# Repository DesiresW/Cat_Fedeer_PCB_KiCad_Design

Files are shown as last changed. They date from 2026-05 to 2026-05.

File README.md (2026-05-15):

# Comedero inteligente para gatos — PCB custom ESP32

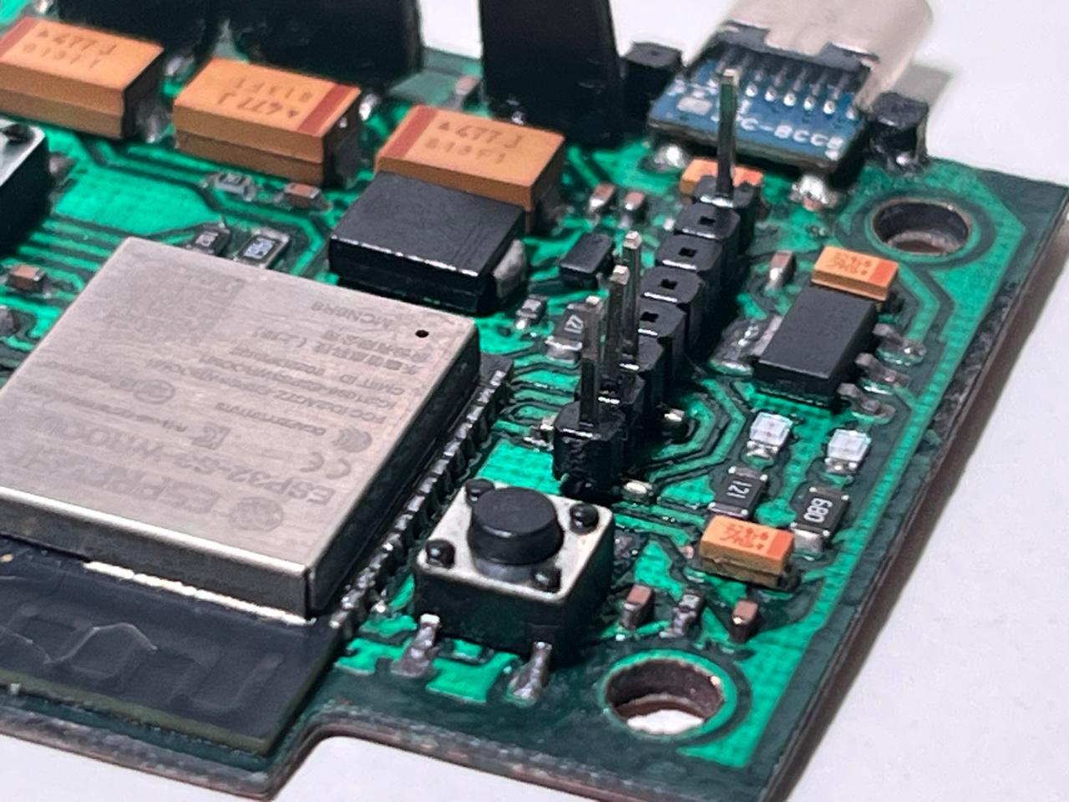
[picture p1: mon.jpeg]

## Descripción general

Este repositorio contiene el diseño de una **PCB custom basada en ESP32-S3** para un prototipo de comedero inteligente para gatos. El objetivo del proyecto no es construir una tarjeta de desarrollo genérica, sino una placa funcional orientada a controlar actuadores, leer sensores y permitir el monitoreo del comportamiento de alimentación de una mascota.

La PCB integra alimentación, programación, conexiones para sensores y actuadores, y módulos externos necesarios para el sistema. El diseño está pensado como una base de prototipado: permite validar el hardware, probar la lógica de control, registrar eventos y preparar una arquitectura donde el firmware pueda incorporar alertas o modelos simples de interpretación de comportamiento.

## Objetivo del proyecto

Diseñar y fabricar una PCB compacta, funcional y soldable que sirva como núcleo electrónico de un comedero para gatos con:

- Control de suministro sólido mediante servomotores.
- Control de motobomba para suministro líquido o sistema auxiliar.
- Medición de distancia mediante sensores ultrasónicos.
- Medición de peso mediante celda de carga y módulo HX711.
- Identificación mediante NFC.
- Alimentación regulada para el ESP32 y periféricos.
- Conexión de desarrollo separada de la conexión pensada para uso final.
- Posibilidad de integrar lógica de alertas e IA embebida en el firmware.

## Esquematico

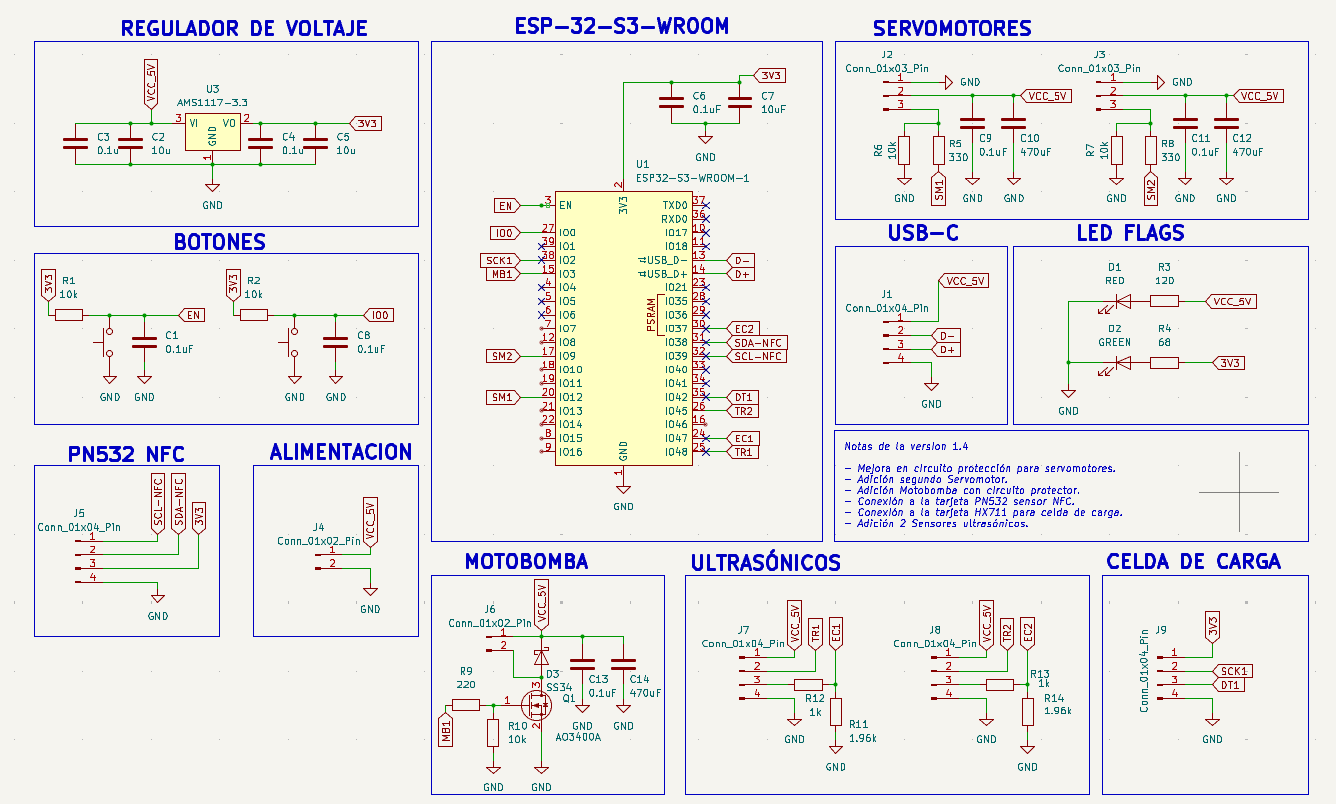
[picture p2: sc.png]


## Estado actual

El proyecto se encuentra en fase de **prototipado físico**. La PCB ya fue diseñada, fabricada, soldada y puesta en pruebas iniciales. Aún se deben validar ajustes eléctricos, mecánicos y de distribución de pines, especialmente en los elementos que dependen de integración con sensores, actuadores y carcasa.

Este repositorio documenta el diseño actual, pero no debe asumirse como una versión final de producto.

## Arquitectura general del sistema

El sistema se organiza alrededor de un microcontrolador ESP32-S3, que actúa como núcleo de control y procesamiento. La placa conecta módulos externos y componentes SMD para manejar lectura sensórica, accionamiento y alimentación.

```text
                 ┌────────────────────────┐
                 │        ESP32-S3         │
                 │  Control + firmware     │
                 └───────────┬────────────┘
                             │
        ┌────────────────────┼────────────────────┐
        │                    │                    │
 ┌──────▼──────┐      ┌──────▼──────┐      ┌──────▼──────┐
 │ Ultrasonido │      │ HX711 +     │      │ PN532 NFC   │
 │ HC-SR04 x2  │      │ celda 1 kg  │      │ + tags NFC  │
 └─────────────┘      └─────────────┘      └─────────────┘
        │                    │                    │
        └────────────────────┼────────────────────┘
                             │
                 ┌───────────▼───────────┐
                 │ Actuadores             │
                 │ Servos + motobomba     │
                 └───────────────────────┘
```

## Funcionalidades previstas

### 1. Control de actuadores

La PCB contempla conexiones para servomotores y para una motobomba controlada mediante MOSFET NMOS. La intención es separar claramente las cargas de potencia del núcleo lógico del ESP32, evitando exigir corriente desde pines o líneas que no están diseñadas para eso.

Los servomotores se plantean para mecanismos de apertura, cierre o dosificación. La motobomba se contempla como actuador auxiliar para suministro líquido o pruebas de dispensación controlada.

### 2. Medición de distancia

Se decidió usar **dos sensores ultrasónicos HC-SR04** en lugar de sensores infrarrojos de bajo costo. La decisión se tomó porque los ultrasónicos entregan una lectura continua de distancia, mientras que varios sensores infrarrojos comerciales económicos solo entregan una señal binaria ajustada por umbral.

En este prototipo, una lectura continua resulta más útil para interpretar niveles, presencia o variaciones en superficies irregulares. Además, el costo de los ultrasónicos era considerablemente menor frente a algunos sensores infrarrojos disponibles comercialmente.

### 3. Medición de peso

El sistema contempla una celda de carga de 1 kg conectada a un módulo HX711. Esta etapa permite medir cambios de peso asociados al alimento o al recipiente.

En este diseño, las conexiones entre la celda de carga y la tarjeta HX711 se consideran externas al esquemático principal de la PCB, por lo que deben revisarse directamente según el módulo y la celda utilizados.

### 4. Identificación NFC

El módulo PN532 y los tags NFC se contemplan para identificación. En el contexto del comedero, esto puede utilizarse para asociar una mascota, un recipiente, una tarjeta de configuración o un evento específico del sistema.

La implementación final depende del firmware y del flujo de uso definido para el prototipo.

### 5. Firmware e IA embebida

El hardware está pensado para recopilar datos de sensores y habilitar una capa de interpretación en firmware. La IA no toma decisiones críticas de control por sí sola; su función prevista es apoyar la clasificación de eventos y generar alertas.

Una posible clasificación de comportamiento puede incluir:

- Estado normal o sin alerta.
- Posible hambre posterior al suministro.
- Rechazo de comida.
- Consumo menor al esperado.
- Consumo mayor al esperado.
- Comportamiento atípico.

Las decisiones de seguridad, apertura, suministro adicional o activación de actuadores deben permanecer en lógica convencional validada.

## Diseño de PCB

### Enfoque

El diseño no busca replicar una DevKit comercial. La PCB fue concebida como una tarjeta específica para el comedero, con las conexiones necesarias para el proyecto y con separación entre uso final y desarrollo.

El diseño prioriza:

- Integración del ESP32-S3 como microcontrolador principal.
- Conexiones para módulos externos.
- Alimentación regulada a 3.3 V.
- Línea de 5 V para periféricos que lo requieran.
- Protección básica en líneas de alimentación y actuadores.
- Componentes SMD para reducir volumen y mejorar integración.
- Conexión de programación separada para facilitar pruebas.

### Conexión de programación

La placa incluye una conexión pensada para desarrollo/programación mediante módulo externo tipo Pololu USB-C. A diferencia de los headers de sensores y actuadores, este conector se mantiene como **macho**, porque es una conexión móvil de desarrollo.

Esta decisión permite conservar una separación entre la interfaz técnica de programación y las conexiones que usaría un usuario final.

### Headers y conectores

Para las footprints de headers se recomienda mantener la lógica definida en el prototipo:

- Headers de sensores y actuadores: **SMD y hembra**.
- Header de programación Pololu: **macho**, con footprint modificada y funcional.
- Verificar siempre el orden de pines de la huella contra el pinout real del módulo, sensor o actuador.

Este punto es crítico porque algunos módulos comerciales no respetan el mismo orden de pines entre fabricantes o versiones.

### Etiquetado de señales

Los labels del diseño se dejaron referenciando al **componente** y no necesariamente al GPIO final. Esta decisión facilita el ruteo y permite cambiar GPIOs durante la organización de pistas sin perder claridad funcional.

Por eso, antes de cerrar una nueva versión, debe revisarse la correspondencia final entre:

- Label del esquemático.
- GPIO asignado.
- Pin físico del ESP32.
- Conector o módulo externo.
- Definición usada en firmware.

## Fabricación de la PCB

La PCB fue fabricada mediante un proceso de prototipado con máquina de fibra. El flujo usado fue:

1. Definición de pistas sobre cobre mediante máquina de fibra.
2. Aplicación de máscara de soldadura sobre la placa.
3. Segunda pasada con la máquina de fibra para retirar la máscara únicamente sobre los pads.
4. Soldadura de componentes SMD y módulos de conexión.
5. Pruebas iniciales de alimentación y funcionamiento.

Este proceso permitió obtener una placa física soldable sin depender de un servicio industrial tradicional de fabricación de PCBs, aunque requiere especial cuidado en pads, continuidad, máscara y tolerancias de soldadura.

## Componentes principales

| Bloque | Componente | Función |
|---|---|---|
| Control | ESP32-S3-WROOM-1-N8R8 | Microcontrolador principal del sistema |
| Alimentación | AMS1117-3.3 | Regulación de 5 V a 3.3 V |
| Programación | Pololu USB-C | Conexión de alimentación/programación para desarrollo |
| Identificación | PN532 NFC | Lectura NFC/RFID |
| Identificación | Tags NTAG213 | Etiquetas NFC para identificación |
| Distancia | HC-SR04 x2 | Medición continua de distancia |
| Peso | HX711 | Conversión y amplificación para celda de carga |
| Peso | Celda de carga 1 kg | Medición de peso |
| Actuación | Servomotores | Apertura/cierre/dosificación |
| Actuación | Motobomba | Suministro líquido o función auxiliar |
| Potencia | AO3400 | Conmutación de motobomba |
| Protección | SS34 | Diodo Schottky para protección |
| Filtrado | Capacitores 100 nF, 10 uF, 470 uF | Estabilidad y desacople |
| Señalización | LEDs SMD | Indicadores de 5 V y 3.3 V |
| Control manual | Pulsadores SMD | Reset y modo programación |

## Lista de referencias de compra

Estos enlaces son referencias de los componentes utilizados o considerados durante el prototipo. Antes de comprar o fabricar una nueva versión, se debe verificar disponibilidad, encapsulado, dimensiones y compatibilidad con la footprint usada en KiCad.

| Componente | Referencia / enlace |
|---|---|
| PN532 NFC | https://www.mercadolibre.com.co/kit-modulo-leitor-rfid-nfc-pn532-com-tag-e-carto/p/MCO2039743778 |
| Tags NFC NTAG213 | https://www.sigmaelectronica.net/producto/ntag213-nfc/ |
| Condensador 470 uF 6.3 V SMD | https://www.sigmaelectronica.net/producto/ct2917-470uf6-3v/ |
| Sensor ultrasónico HC-SR04 | https://www.sigmaelectronica.net/producto/hc-sr04/ |
| Tarjeta HX711 | https://www.sigmaelectronica.net/producto/tarjeta-hx711/ |
| Celda de carga 1 kg | https://www.sigmaelectronica.net/producto/celda-1k/ |
| Diodo SS34 | https://www.sigmaelectronica.net/producto/ss34/ |
| MOSFET AO3400 | https://www.mercadolibre.com.co/mosfet-ao3400-a09t-sot23-smd-x-5-unidades/up/MCOU3179338761 |
| Resistencia SMD 220 Ω | https://www.sigmaelectronica.net/producto/r1206-220-ohm/ |
| Resistencia SMD 1 kΩ | https://www.sigmaelectronica.net/producto/r0805-1k/ |
| Resistencia SMD 1.96 kΩ | https://www.sigmaelectronica.net/producto/p1-96kect/ |

## Inventario resumido de soldables

La siguiente lista resume los elementos principales identificados para fabricación de varias unidades del prototipo. Las cantidades exactas deben revisarse contra el Excel de inventario y la versión actual del esquemático.

| Elemento | Valor / referencia | Encapsulado o formato | Cantidad por PCB |
|---|---:|---|---:|
| Capacitor | 0.1 uF | 0603 | 6 |
| Capacitor | 10 uF | 1206 | 3 |
| Capacitor | 470 uF | SMD | 3 |
| LED | Rojo | 0805 | 1 |
| LED | Verde | 0805 | 1 |
| Diodo | SS34 | SMC / DO-214AB | 1 |
| Header macho | Programación | SMD, mínimo 8 pines | 1 |
| Header hembra | 3 pines | SMD | 2 |
| Header hembra | 4 pines | SMD | 4 |
| Header hembra | 2 pines | SMD | 1 |
| Conector/fuente | JRC-B008 | SMD | 1 |
| MOSFET | AO3400A | SOT-23 | 1 |
| Resistencia | 10 kΩ | 0603 | 5 |
| Resistencia | 120 Ω | 1206 | 1 |
| Resistencia | 68 Ω | 1206 | 1 |
| Resistencia | 330 Ω | 0805 | 2 |
| Resistencia | 220 Ω | 1206 | 1 |
| Resistencia | 1.96 kΩ | 1206 | 2 |
| Resistencia | 1 kΩ | 0805 | 2 |
| Pulsador | Switch SMD | SMD | 2 |
| Regulador | AMS1117-3.3 | SOT-223-3 | 1 |
| MCU | ESP32-S3-WROOM-1-N8R8 | Módulo SMD | 1 |

## Módulos externos considerados

| Módulo | Cantidad por PCB | Observación |
|---|---:|---|
| PN532 NFC | 1 | Módulo externo para lectura NFC |
| Motobomba | 1 | Controlada mediante MOSFET |
| HC-SR04 | 2 | Lecturas continuas de distancia |
| Celda de carga | 1 | Conectada al HX711 |
| HX711 | 1 | Módulo de lectura para celda de carga |
| Pololu programador | 1 | Uso de desarrollo/programación |
| Header hembra Pololu | 1 | Revisar orientación y pinout |
| Servomotores | 2 | Conectores dedicados |

## Recomendaciones de diseño y revisión

### Footprints

Antes de fabricar una nueva revisión de la PCB, revisar cuidadosamente:

- Que el encapsulado del componente comprado coincida con la footprint usada.
- Que las resistencias y capacitores SMD coincidan en tamaño real con el diseño.
- Que los headers SMD tengan la orientación correcta.
- Que el orden de pines de cada módulo coincida con la huella.
- Que los pads expuestos después de la máscara de soldadura sean suficientes para soldar cómodamente.
- Que el módulo ESP32 tenga área libre adecuada para antena.

### Inventario y Excel

Para actualizar el Excel del proyecto, conviene agrupar los componentes por valor y encapsulado. No es necesario repetir cada resistencia o capacitor en filas separadas si tienen el mismo valor y la misma footprint.

Una estructura útil sería:

| Componente | Valor | Encapsulado | Cantidad por PCB | Cantidad a fabricar | Total requerido | Disponible | Faltante | Tienda | Link |
|---|---|---|---:|---:|---:|---:|---:|---|---|

También es recomendable separar la lista por tienda:

- Sigma Electrónica: mayoría de resistencias, capacitores, sensores y módulos.
- Mercado Libre: PN532 y MOSFET AO3400, si no se consigue localmente en otra tienda.
- Electronilab: ESP32-S3-WROOM-1-N8R8, según disponibilidad.
- Otro proveedor: headers SMD hembra/macho si no están disponibles en Sigma.

### Alimentación

El diseño incluye regulación para 3.3 V y líneas de alimentación para periféricos. Como recomendación general:

- No alimentar servomotores ni motobomba desde el pin de 3.3 V del ESP32.
- Separar cargas de potencia y lógica siempre que sea posible.
- Usar capacitores de desacople cerca de alimentación del microcontrolador y módulos sensibles.
- Revisar caída de tensión cuando se activen actuadores.
- Validar temperatura del regulador durante pruebas.
- Confirmar continuidad y ausencia de cortos antes de montar el ESP32.

### Sensores ultrasónicos

Los sensores HC-SR04 operan típicamente a 5 V. Antes de conectar la señal `Echo` al ESP32, se debe revisar si se requiere adaptación de nivel hacia 3.3 V para proteger el pin del microcontrolador.

### Motobomba y MOSFET

Para la motobomba se contempla un MOSFET NMOS AO3400. La etapa debe revisarse con especial atención en:

- Corriente real de la motobomba.
- Diodo de protección.
- Tierra común entre lógica y potencia.
- Ancho de pista para corriente.
- Temperatura del MOSFET en funcionamiento.
- Separación entre señal de control y carga inductiva.

### Celda de carga y HX711

La celda de carga se conecta a la tarjeta HX711. En este repositorio, las conexiones entre celda y HX711 se consideran parte del cableado externo del módulo, no del esquemático principal de la PCB.

Antes de calibrar el sistema se debe:

- Verificar cableado de la celda.
- Confirmar orientación de alimentación.
- Probar lectura cruda del HX711.
- Calibrar con pesos conocidos.
- Registrar factor de calibración en firmware.

## Estructura sugerida del repositorio

```text
.
├── README.md
├── hardware/
│   ├── kicad/
│   │   ├── esquematico/
│   │   ├── pcb/
│   │   └── gerbers/
│   ├── renders/
│   └── fabricacion/
├── firmware/
│   ├── src/
│   ├── include/
│   └── README.md
├── docs/
│   ├── img/
│   │   └── pcb-soldada.jpg
│   ├── inventario/
│   └── pruebas/
└── tools/
    └── scripts/
```

Esta estructura es solo una recomendación para mantener separados el diseño electrónico, el firmware, las imágenes, la documentación y los archivos auxiliares.

## Pruebas recomendadas

Antes de conectar todos los módulos al mismo tiempo, se recomienda validar por etapas:

### 1. Prueba de continuidad

- Verificar continuidad de GND.
- Verificar ausencia de corto entre 5 V y GND.
- Verificar ausencia de corto entre 3.3 V y GND.
- Revisar continuidad de EN, IO0 y líneas de programación.
- Revisar pads expuestos y soldaduras frías.

### 2. Prueba de alimentación

- Energizar sin ESP32 si el diseño lo permite.
- Medir 5 V.
- Medir 3.3 V.
- Revisar temperatura del regulador.
- Confirmar comportamiento de LEDs de alimentación.
- Medir consumo en reposo.

### 3. Prueba de programación

- Conectar programador.
- Verificar enumeración USB/serial.
- Probar modo boot.
- Cargar firmware mínimo.
- Confirmar salida serial.

### 4. Prueba de sensores

- Leer HC-SR04 individualmente.
- Leer HX711 sin carga.
- Calibrar celda de carga.
- Probar PN532 con tag NFC.
- Registrar estabilidad de lecturas.

### 5. Prueba de actuadores

- Probar servos por separado.
- Probar motobomba con fuente adecuada.
- Confirmar que la activación de actuadores no reinicie el ESP32.
- Medir caída de tensión durante activación.
- Revisar ruido eléctrico o reinicios.

### 6. Prueba integrada

- Ejecutar un ciclo de alimentación simulado.
- Registrar distancia, peso y eventos.
- Probar identificación NFC.
- Validar que las alertas del firmware no activen cargas sin pasar por lógica convencional.
- Documentar errores encontrados para la siguiente revisión.

## Pendientes

- Validar pinout final de todos los headers.
- Confirmar si se requiere adaptación de nivel para señales de sensores a 5 V.
- Ajustar GPIOs según facilidad de ruteo y estabilidad del firmware.
- Documentar esquema final de alimentación.
- Subir fotografías del PCB soldado.
- Agregar capturas del esquemático y layout.
- Publicar archivos KiCad organizados.
- Documentar pruebas eléctricas realizadas.
- Documentar calibración de celda de carga.
- Definir estructura final del firmware.
- Separar con claridad la lógica convencional de la capa de IA.

## Advertencia

Este proyecto está en fase de prototipado. No debe usarse como circuito final sin validar alimentación, consumo, temperatura, aislamiento, protección, corriente de actuadores y seguridad mecánica. Cualquier modificación debe revisarse en esquemático, PCB y firmware antes de energizar la placa.

## Créditos

Proyecto desarrollado como ejercicio de diseño de PCB custom, sistemas embebidos e integración sensórica aplicada a un comedero inteligente para gatos.

El diseño toma como punto de partida la idea de construir una placa propia con ESP32, pero adapta el hardware a una aplicación específica: monitoreo y control de alimentación animal mediante sensores, actuadores y procesamiento embebido.

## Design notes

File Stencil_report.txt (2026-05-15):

PCB statistics report
=====================
- Date: 6/05/2026 9:40:05 a. m.
- Project: Stencil
- Board name: Stencil

Board
-----
- Width: 60,0100 mm
- Height: 50,2500 mm
- Area: 2805,2250 mm²

Pads
----
- Through hole: 12
- SMD: 157
- Connector: 0
- NPTH: 0

Vias
----
- Through vias: 0
- Blind/buried: 0
- Micro vias: 0

Components
----------

| | Front Side | Back Side | Total |
|---|---|---|---|
|THT: | 0 | 0 | 0 |
|SMD: | 45 | 0 | 45 |
|Unspecified:  | 0 | 0 | 0 |
|Total: | 45 | 0 | 45 |

Drill holes
-----------

| Count | Shape | X Size | Y Size | Plated | Via/Pad | Start Layer | Stop Layer |
|---|---|---|---|---|---|---|---|
| 12 | Round | 0,2000 mm | 0,2000 mm | PTH | Pad | F.Cu | B.Cu |

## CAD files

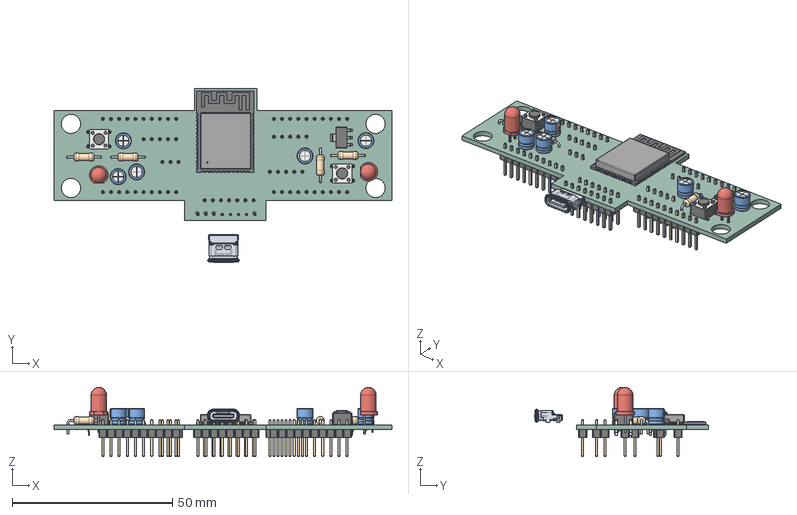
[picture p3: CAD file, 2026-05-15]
Assets/Comedero_V1.4/Stencil.step
105.4 x 54.2 x 21.6 mm
PinHeader_1x10_P2.54mm_Vertical x 4
ESP32-S3-WROOM-1
CP_Radial_D5.0mm_P2.00mm x 5
SW_PUSH_6mm x 2
PinHeader_1x03_P2.54mm_Vertical
PinHeader_1x07_P2.54mm_Vertical
PinHeader_1x08_P2.54mm_Vertical
R_Axial_DIN0207_L6.3mm_D2.5mm_P10.16mm_Horizontal x 4
LED_D5.0mm x 2
PinHeader_1x05_P2.54mm_Vertical x 3
SOT-223
Stencil_PCB

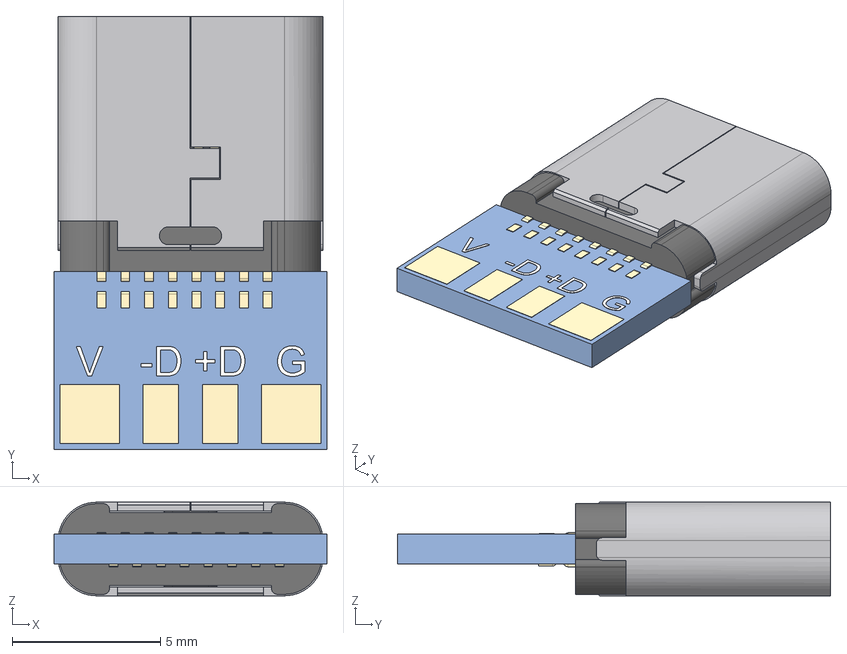
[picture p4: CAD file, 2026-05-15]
Assets/Comedero_V1.4/usb-c-female-jrc-b008-1.snapshot.5/USB-C board JRC-B023.step
9.20 x 14.6 x 3.16 mm
USB_C_SHELL
USB_C_Body
USB_C_PIN x 16
PCB board
text
Contacts

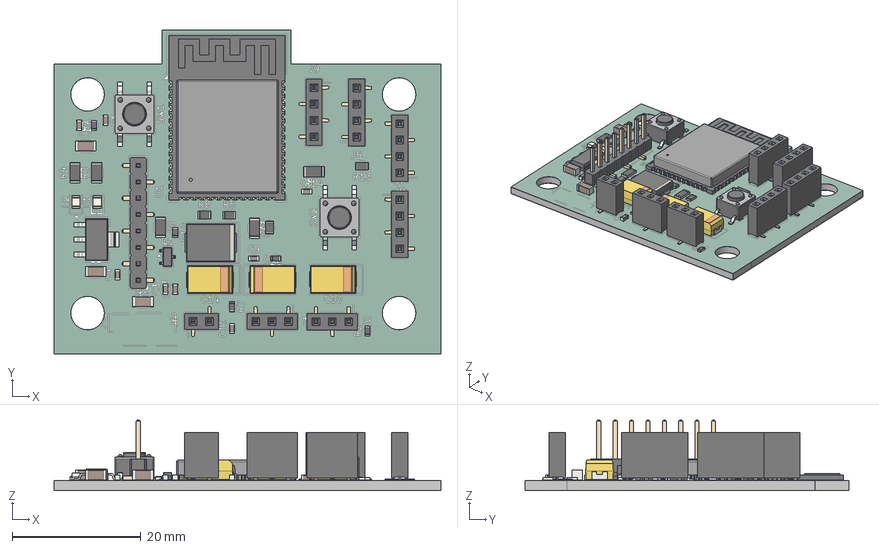
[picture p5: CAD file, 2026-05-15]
Stencil.step
60.0 x 50.2 x 10.9 mm
LED_0805_2012Metric x 2
PinSocket_1x03_P2.54mm_Vertical_SMD_Pin1Left x 2
C_1206_3216Metric x 3
R_0805_2012Metric x 4
R_1206_3216Metric x 5
CP_EIA-7343-31_Kemet-D x 3
SOT-223
PinSocket_1x04_P2.54mm_Vertical_SMD_Pin1Left x 2
C_0603_1608Metric x 8
PinSocket_1x02_P2.54mm_Vertical_SMD_Pin1Left
PinHeader_1x08_P2.54mm_Vertical_SMD_Pin1Left
PinSocket_1x04_P2.54mm_Vertical_SMD_Pin1Right x 2
SOT-23
R_0603_1608Metric x 5
D_SMC
ESP32-S3-WROOM-1
SW_Push_1P1T_NO_E-Switch_TL3301NxxxxxG x 2
Stencil_silkscreen
Stencil_soldermask x 2
Stencil_PCB

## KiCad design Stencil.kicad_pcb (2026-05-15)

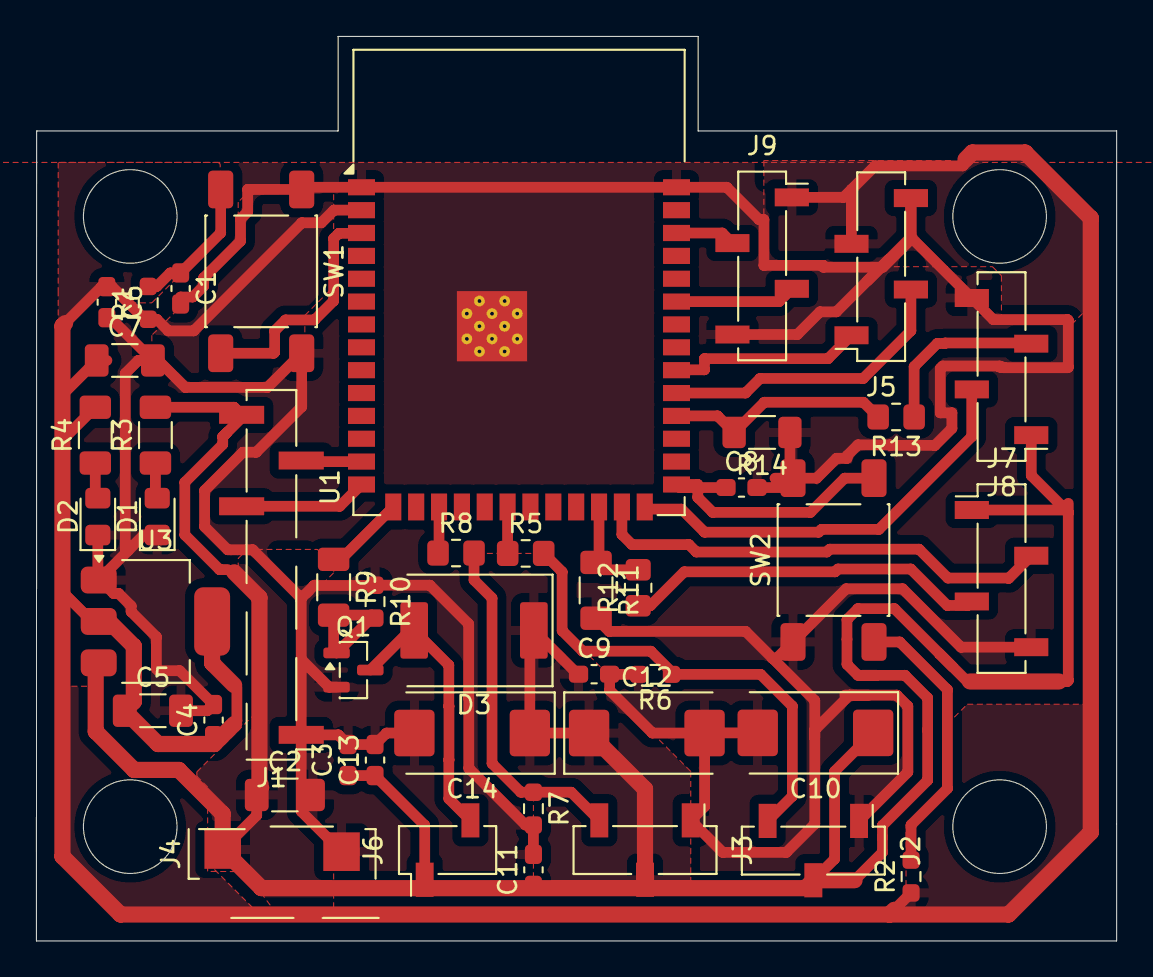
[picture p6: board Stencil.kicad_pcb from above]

Board: 2 copper layers, 60.0 x 50.2 mm, 45 parts (0 on the bottom side), 26 nets.

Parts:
C1, C6, C8, C9, C11, C13: 0.1uF; C_0603_1608Metric_Pad1.08x0.95mm_HandSolder
C2, C5: 10u; C_1206_3216Metric_Pad1.33x1.80mm_HandSolder
C3, C4: 0.1u; C_0603_1608Metric_Pad1.08x0.95mm_HandSolder
C7: 10uF; C_1206_3216Metric_Pad1.33x1.80mm_HandSolder
C10, C12, C14: 470uF; CP_EIA-7343-31_Kemet-D_HandSolder
D1: RED; LED_0805_2012Metric_Pad1.15x1.40mm_HandSolder
D2: GREEN; LED_0805_2012Metric_Pad1.15x1.40mm_HandSolder
D3: SS34; ST_D_SMC
J1: Conn_01x04_Pin; pololu
J2: Servo 2; PinSocket_1x03_P2.54mm_Vertical_SMD_Pin1Left
J3: Servo 1; PinSocket_1x03_P2.54mm_Vertical_SMD_Pin1Left
J4: Conn_01x02_Pin; JRC-B008
J5: Sensor NFC ↓; PinSocket_1x04_P2.54mm_Vertical_SMD_Pin1Right
J6: Motobomba; PinSocket_1x02_P2.54mm_Vertical_SMD_Pin1Left
J7: Ultrasónico 1; PinSocket_1x04_P2.54mm_Vertical_SMD_Pin1Left
J8: Ultrasónico 2; PinSocket_1x04_P2.54mm_Vertical_SMD_Pin1Left
J9: ↑Celda_Carga; PinSocket_1x04_P2.54mm_Vertical_SMD_Pin1Right
Q1: NMOS ↓; SOT-23
R1, R2, R6, R7, R10: 10k; R_0603_1608Metric_Pad0.98x0.95mm_HandSolder
R3: 120; R_1206_3216Metric_Pad1.30x1.75mm_HandSolder
R4: 68; R_1206_3216Metric_Pad1.30x1.75mm_HandSolder
R5, R8: 330; R_0805_2012Metric_Pad1.20x1.40mm_HandSolder
R9: 220; R_1206_3216Metric_Pad1.30x1.75mm_HandSolder
R11, R14: 1.96k; R_1206_3216Metric_Pad1.30x1.75mm_HandSolder
R12, R13: 1k; R_0805_2012Metric_Pad1.20x1.40mm_HandSolder
SW1: Reinicio; SW_Push_1P1T_NO_E-Switch_TL3301NxxxxxG
SW2: Programar; SW_Push_1P1T_NO_E-Switch_TL3301NxxxxxG
U1: ESP32-S3-WROOM-1
U3: AMS1117-3.3; SOT-223-3_TabPin2

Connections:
3V3: C4.1, C5.1, C6.1, C7.1, J5.3, J9.1, R1.1, R2.1, R4.2, U1.2 (3V3), U3.2 (VO)
D+: J1.3, U1.14 (USB_D+)
D-: J1.2, U1.13 (USB_D-)
DT1: J9.3, U1.35 (IO42)
EC1: R11.1, R12.2, U1.24 (IO47)
EC2: R13.2, R14.2, U1.30 (IO37)
EN: C1.1, R1.2, SW1.2, U1.3 (EN)
GND: C1.2, C2.2, C3.2, C4.2, C5.2, C6.2, C7.2, C8.2, C9.2, C10.2, C11.2, C12.2, C13.2, C14.2, D1.1 (K), D2.1 (K), J1.4, J2.1, J3.1, J4.2, J5.4, J7.4, J8.4, J9.4, Q1.2 (S), R6.2, R7.2, R10.1, R11.2, R14.1, SW1.1, SW2.1, U1.1 (GND), U1.40 (GND), U1.41 (GND), U3.1 (GND)
IO0: C8.1, R2.2, SW2.2, U1.27 (IO0)
MB1: R9.1, U1.15 (IO3)
unnamed: D1.2 (A), R3.1
unnamed: D2.2 (A), R4.1
unnamed: D3.2 (A), J6.2, Q1.3 (D)
unnamed: J2.3, R5.2, R6.1
unnamed: J3.3, R7.1, R8.2
unnamed: J7.3, R12.1
unnamed: J8.3, R13.1
unnamed: Q1.1 (G), R9.2, R10.2
SCK1: J9.2, U1.38 (IO2)
SCL-NFC: J5.1, U1.32 (IO39)
SDA-NFC: J5.2, U1.31 (IO38)
SM1: R5.1, U1.20 (IO12)
SM2: R8.1, U1.17 (IO9)
TR1: J7.2, U1.25 (IO48)
TR2: J8.2, U1.26 (IO45)
VCC_5V: C2.1, C3.1, C9.1, C10.1, C11.1, C12.1, C13.1, C14.1, D3.1 (K), J1.1, J2.2, J3.2, J4.1, J6.1, J7.1, J8.1, R3.2, U3.3 (VI)

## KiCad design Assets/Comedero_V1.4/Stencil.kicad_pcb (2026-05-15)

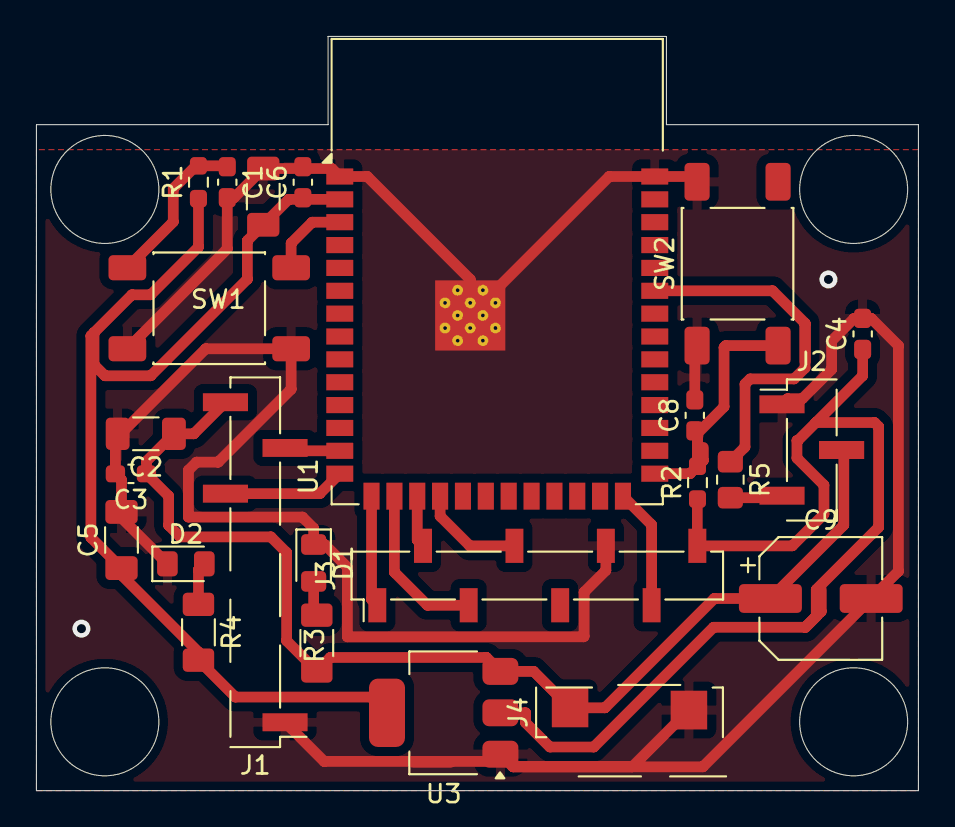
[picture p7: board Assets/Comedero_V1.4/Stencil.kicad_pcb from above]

Board: 2 copper layers, 49.0 x 41.9 mm, 24 parts (0 on the bottom side), 15 nets.

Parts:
C1, C6, C8: 0.1uF; C_0603_1608Metric_Pad1.08x0.95mm_HandSolder
C2, C5: 10u; C_1206_3216Metric_Pad1.33x1.80mm_HandSolder
C3, C4: 0.1u; C_0603_1608Metric_Pad1.08x0.95mm_HandSolder
C7: 10uF; C_1206_3216Metric_Pad1.33x1.80mm_HandSolder
C9: 100uF; CP_Elec_6.3x5.4
D1: RED; LED_0805_2012Metric_Pad1.15x1.40mm_HandSolder
D2: GREEN; LED_0805_2012Metric_Pad1.15x1.40mm_HandSolder
J1: Conn_01x04_Pin; PinHeader_1x08_P2.54mm_Vertical_SMD_Pin1Left
J2: Conn_01x03_Pin; PinHeader_1x03_P2.54mm_Vertical_SMD_Pin1Left
J3: Conn_01x08_Socket; PinSocket_1x08_P2.54mm_Vertical_SMD_Pin1Left
J4: Conn_01x02_Pin; PinHeader_1x04_P2.54mm_Vertical_SMD_Pin1Left
R1, R2: 10k; R_0603_1608Metric_Pad0.98x0.95mm_HandSolder
R3: 120; R_1206_3216Metric_Pad1.30x1.75mm_HandSolder
R4: 68; R_1206_3216Metric_Pad1.30x1.75mm_HandSolder
R5: 330; R_0805_2012Metric_Pad1.20x1.40mm_HandSolder
SW1, SW2: SW_Push; SW_Push_1P1T_NO_E-Switch_TL3301NxxxxxG
U1: ESP32-S3-WROOM-1
U3: AMS1117-3.3; SOT-223-3_TabPin2

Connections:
3V3: C4.1, C5.1, C6.1, C7.1, J3.8, R1.1, R2.1, R4.2, U1.2 (3V3), U3.2 (VO)
D+: J1.3, U1.14 (USB_D+)
D-: J1.2, U1.13 (USB_D-)
EN: C1.1, R1.2, SW1.2, U1.3 (EN)
GND: C1.2, C2.2, C3.2, C4.2, C5.2, C6.2, C7.2, C8.2, C9.2, D1.1 (K), D2.1 (K), J1.4, J2.1, J3.6, J4.2, SW1.1, SW2.1, U1.1 (GND), U1.40 (GND), U1.41 (GND), U3.1 (GND)
GPIO_15: J3.1, U1.15 (IO3)
GPIO_16: J3.3, U1.16 (IO46)
GPIO_17: J3.2, U1.17 (IO9)
GPIO_18: J3.4, U1.18 (IO10)
GPIO_26: J3.7, U1.26 (IO45)
IO0: C8.1, R2.2, SW2.2, U1.27 (IO0)
unnamed: D1.2 (A), R3.1
unnamed: D2.2 (A), R4.1
unnamed: J2.3, R5.2
VCC_5V: C2.1, C3.1, C9.1, J1.1, J2.2, J4.1, R3.2, U3.3 (VI)

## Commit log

2026-05-15 Primer commit: diseño PCB comedero para gatos
    [Stencil-B_Cu.gbr, Stencil-B_Mask.gbr, Stencil-B_Paste.gbr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]
2026-05-15 Change PCB image paths in README.md
    Updated image references in README for PCB prototype.
2026-05-15 Fix image path for PCB prototype
    Update image path for PCB prototype in README
2026-05-15 Replace PCB image and add schematic section
    Updated images in README and added schematic section.
